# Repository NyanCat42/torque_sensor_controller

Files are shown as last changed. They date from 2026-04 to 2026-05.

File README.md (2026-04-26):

# Torque Sensor Controller for VESC E-Bike Assist

This repository contains hardware and firmware for an ESP32-S3 based torque sensor controller that talks to a [VESC](https://github.com/vedderb/bldc) over CAN bus.

The controller reads bottom bracket torque and cadence, computes an assist current target, and sends motor current commands to the VESC. It also tracks odometer data with FRAM-backed persistence and exposes a local web UI for status, tuning, and OTA firmware updates.

## Features

- Torque and cadence based pedal-assist control loop (10 ms period).
- CAN communication to VESC at 500 kbit/s.
- Odometer and speed tracking with persistent FRAM storage.
- Wi-Fi station mode with fallback access point mode.
- Embedded HTTP console for telemetry, runtime config, and calibration.
- OTA firmware upload endpoint.
- TCP bridge for VESC tool connectivity over Wi-Fi.

## Repository Layout

- `lauryno_torque_controller_hardware/`: KiCad schematic, PCB, and BOM.
- `lauryno_torque_controller_software/`: PlatformIO firmware project.
- `documents/`: reference documents, including [torque sensor datasheet](./documents/S135daff485444e569ac136541eaddd83u.pdf).
- `images/`: board render and finished board photo.

## Hardware

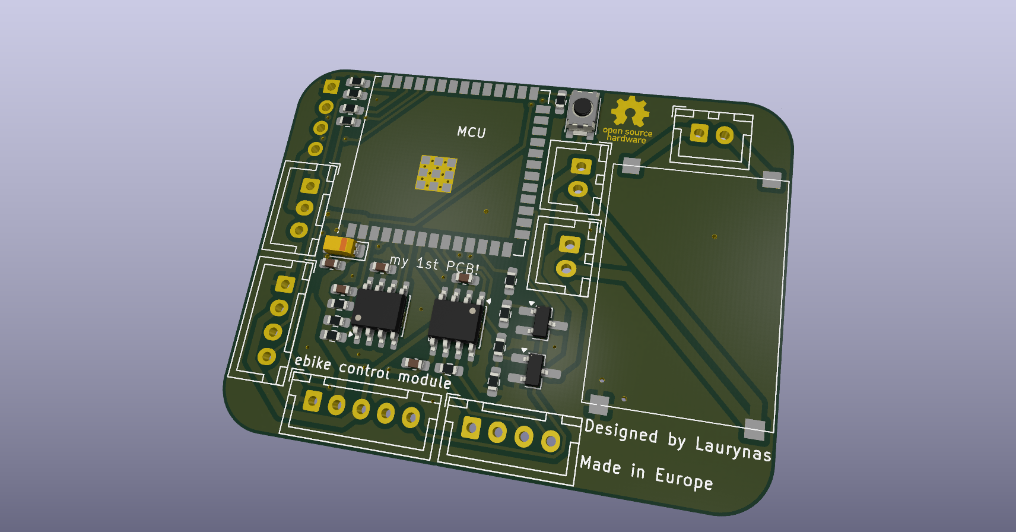
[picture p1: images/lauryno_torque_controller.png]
PCB render


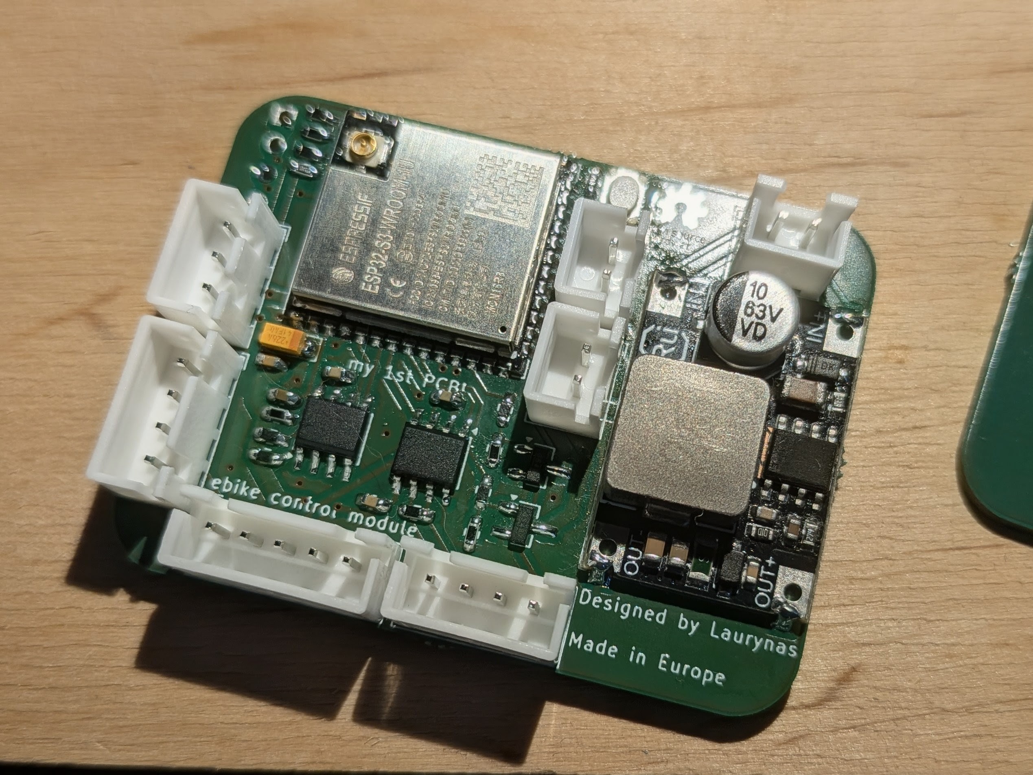
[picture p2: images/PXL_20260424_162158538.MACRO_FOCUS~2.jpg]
Finished PCB


Hardware highlights:

- ESP32-S3 module as main controller.
- CAN transceiver interface to VESC.
- FRAM storage for high-endurance persistent data.
- 2 MOSFET outputs and a buck stage for front/rear LED lighting.

The PCB was designed to fit AISLER simple 2-layer constraints for low-cost fabrication.

Available hardware design artifacts:

- Schematic: [lauryno_torque_controller.kicad_sch](./lauryno_torque_controller_hardware/lauryno_torque_controller.kicad_sch)
- PCB layout: [lauryno_torque_controller.kicad_pcb](./lauryno_torque_controller_hardware/lauryno_torque_controller.kicad_pcb)
- BOM: [lauryno_torque_controller.csv](./lauryno_torque_controller_hardware/lauryno_torque_controller.csv)

## Firmware Architecture

Main runtime modules:

- `PedalAssistManager`: torque/cadence processing and motor current command generation.
- `VescCan`: CAN transport and VESC status/current command handling.
- `OdometerManager`: wheel pulse tracking, speed estimation, and persistence.
- `FramStorage`: I2C FRAM read/write backend.
- `NetworkManager`: station connect with timeout and fallback AP startup.
- `OtaHttpServer`: web UI, REST endpoints, and OTA upload flow.
- `VescTcpBridge`: optional TCP bridge (disabled by default).

Task model:

- Pedal-assist control task on core 1.
- Communication task (HTTP + TCP bridge update loop) on core 0.
- Main loop polls CAN and updates odometer processing.

## Quick Start

First flash has to be done over UART, later ones can be done OTA.

1. Install PlatformIO CLI.
2. Open terminal in `lauryno_torque_controller_software/`.
3. Create a local `platformio.secrets.ini` (this file is git-ignored):

```ini
[env:esp32-s3-devkitc-1]
build_flags =
	-DWIFI_STA_SSID=\"YOUR_WIFI_SSID\"
	-DWIFI_STA_PASSWORD=\"YOUR_WIFI_PASSWORD\"
```

4. Build firmware:

```bash
pio run -e esp32-s3-devkitc-1
```

5. Upload over UART (pads at top left of board):

```bash
pio run -e esp32-s3-devkitc-1 -t upload
```

## First Boot Notes

- Device tries configured Wi-Fi STA first, then falls back to AP mode if connection times out.
- AP SSID format: `TorqueCtrl-Setup-<chipid>`.
- mDNS host: `lauryno-dviratis.local`.
- HTTP console runs on port `80`.
- VESC TCP bridge port: `65102` (can be toggled from API/UI).
- **Run pedal sensor zero calibration** after installation using `POST /api/pedal/calibrate_zero`.

## OTA Update

Firmware can be uploaded from the web UI or directly by HTTP multipart upload:

```bash
curl -F "file=@.pio/build/esp32-s3-devkitc-1/firmware.bin" http://lauryno-dviratis.local/api/update
```

After a successful upload, the controller restarts automatically.

## Configuration Baseline

Hardware pins:

- CAN: TX GPIO 15, RX GPIO 7, 500000 bit/s.
- Odometer hall input: GPIO 9.
- FRAM I2C: SDA GPIO 6, SCL GPIO 5, base address `0x50`.
- Torque ADC input: GPIO 1.
- Cadence input: GPIO 2.

VESC IDs: 

- Local controller `42`, target controller `69` (make sure this matches the CAN ID of your VESC).

See `lauryno_torque_controller_software/include/app_config.h` for the full set of constants and limits.

## Open-Source License

This project is licensed under **CERN Open Hardware Licence Version 2 - Permissive** (`CERN-OHL-P-2.0`).

See the repository [LICENSE](./LICENSE) file for the project license notice and the official CERN-OHL-P v2 text reference.

## References

- VESC firmware project: [https://github.com/vedderb/bldc](https://github.com/vedderb/bldc)
- Torque sensor reference document: [S135daff485444e569ac136541eaddd83u.pdf](./documents/S135daff485444e569ac136541eaddd83u.pdf)

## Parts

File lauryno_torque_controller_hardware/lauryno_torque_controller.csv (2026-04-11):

Reference | Qty | Value | DNP | Exclude from BOM | Exclude from Board | Footprint | Datasheet
Battery1,LED1,LED2 | 3 | Conn_01x02_Socket |  |  |  | Connector_JST:JST_XH_B2B-XH-A_1x02_P2.50mm_Vertical
Boot1 | 1 | SW_Push |  |  |  | Button_Switch_SMD:SW_Push_SPST_NO_Alps_SKRK
C2,C4,C5,C6 | 4 | 0.1u |  |  |  | Capacitor_SMD:C_0603_1608Metric_Pad1.08x0.95mm_HandSolder
C3 | 1 | 1u |  |  |  | Capacitor_SMD:C_0603_1608Metric_Pad1.08x0.95mm_HandSolder
C7 | 1 | 22u |  |  |  | Capacitor_Tantalum_SMD:CP_EIA-3216-18_Kemet-A_HandSolder
CAN_chip1 | 1 | TJA1051T-3 |  |  |  | Package_SO:SOIC-8_3.9x4.9mm_P1.27mm | http://www.nxp.com/docs/en/data-sheet/TJA1051.pdf
Chineesium_60V_to_12V1 | 1 | Conn_01x04_Pin |  |  |  | Connector_PinHeader_2.54mm:PinHeader_1x04_P2.54mm_Vertical
ESP32 | 1 | ESP32-S3-WROOM-1 |  |  |  | RF_Module:ESP32-S3-WROOM-1U | https://www.espressif.com/sites/default/files/documentation/esp32-s3-wroom-1_wroom-1u_datasheet_en.pdf
Flashing_UART1 | 1 | Conn_01x04_Socket |  |  |  | Connector_PinHeader_2.54mm:PinHeader_1x04_P2.54mm_Vertical
FRAM1 | 1 | FM24CL16B |  |  |  | Package_SO:SOIC-8_3.9x4.9mm_P1.27mm | https://www.infineon.com/dgdl/Infineon-FM24CL16B_16-Kbit_(2_K_8)_Serial_(I2C)_F-RAM-DataSheet-v13_00-EN.pdf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
Q1,Q2 | 2 | IRLML2502TRPBF |  |  |  | Package_TO_SOT_SMD:SOT-23_Handsoldering | https://www.infineon.com/dgdl/irlml2060pbf.pdf?fileId=5546d462533600a401535664b7fb25ee
R1,R4,R7,R8,R9,R12 | 6 | 10k |  |  |  | Resistor_SMD:R_0603_1608Metric_Pad0.98x0.95mm_HandSolder
R2 | 1 | 120 |  |  |  | Resistor_SMD:R_0603_1608Metric_Pad0.98x0.95mm_HandSolder
R5,R6 | 2 | 220 |  |  |  | Resistor_SMD:R_0603_1608Metric_Pad0.98x0.95mm_HandSolder
R10,R11 | 2 | 15k |  |  |  | Resistor_SMD:R_0603_1608Metric_Pad0.98x0.95mm_HandSolder
R13,R14 | 2 | 4.7k |  |  |  | Resistor_SMD:R_0603_1608Metric_Pad0.98x0.95mm_HandSolder
Throttle1 | 1 | Conn_01x03_Socket |  |  |  | Connector_JST:JST_XH_B3B-XH-A_1x03_P2.50mm_Vertical
Torque_sensor1,VESC_coms1 | 2 | Conn_01x04_Socket |  |  |  | Connector_JST:JST_XH_B4B-XH-A_1x04_P2.50mm_Vertical
VESC1 | 1 | Conn_01x05_Socket |  |  |  | Connector_JST:JST_XH_B5B-XH-A_1x05_P2.50mm_Vertical

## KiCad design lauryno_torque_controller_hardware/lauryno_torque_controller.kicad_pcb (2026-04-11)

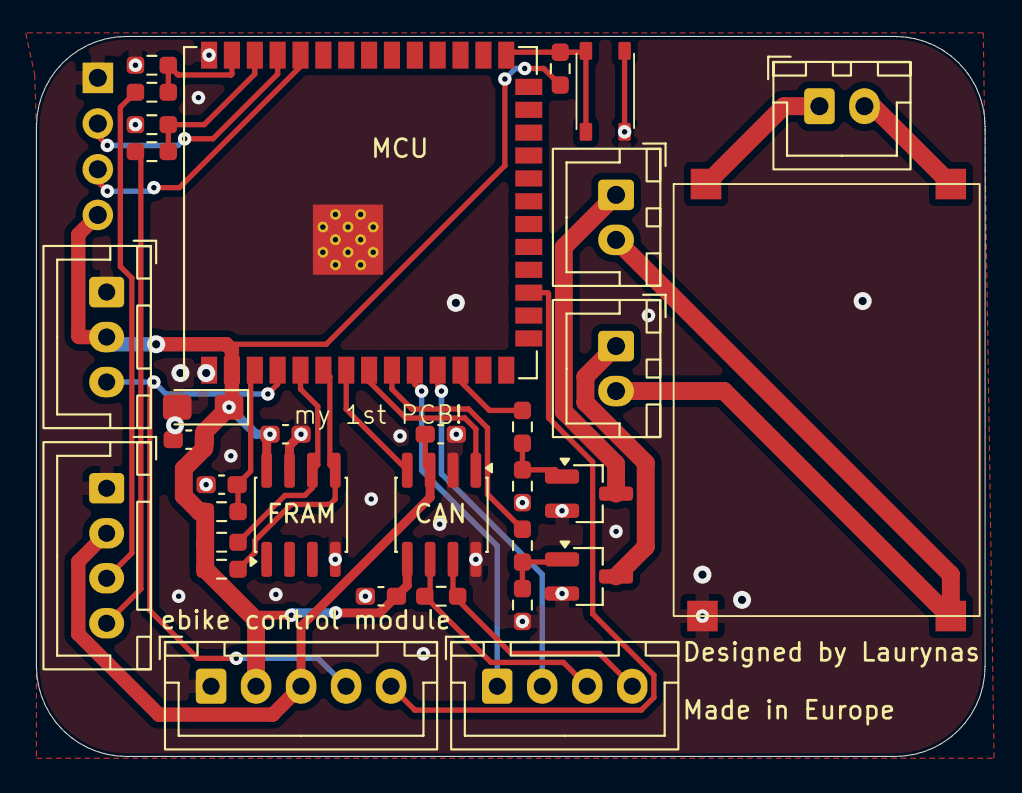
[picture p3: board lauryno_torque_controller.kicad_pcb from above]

Board: 2 copper layers, 52.7 x 40.0 mm, 34 parts (0 on the bottom side), 27 nets.

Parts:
Battery1: Conn_01x02_Socket; JST_XH_B2B-XH-A_1x02_P2.50mm_Vertical
Boot1: SW_Push; SW_Push_SPST_NO_Alps_SKRK
C2, C4, C5, C6: 0.1u; C_0603_1608Metric_Pad1.08x0.95mm_HandSolder
C3: 1u; C_0603_1608Metric_Pad1.08x0.95mm_HandSolder
C7: 22u; CP_EIA-3216-18_Kemet-A_HandSolder
CAN_chip1: TJA1051T-3; SOIC-8_3.9x4.9mm_P1.27mm
Chineesium_60V_to_12V1: Conn_01x04_Pin; PinHeader_1x04_P2.54mm_Vertical
ESP32: ESP32-S3-WROOM-1; ESP32-S3-WROOM-1U
FRAM1: FM24CL16B; SOIC-8_3.9x4.9mm_P1.27mm
Flashing_UART1: Conn_01x04_Socket; PinHeader_1x04_P2.54mm_Vertical
LED1, LED2: Conn_01x02_Socket; JST_XH_B2B-XH-A_1x02_P2.50mm_Vertical
Q1, Q2: IRLML2502TRPBF; SOT-23_Handsoldering
R1, R4, R7, R8, R9, R12: 10k; R_0603_1608Metric_Pad0.98x0.95mm_HandSolder
R2: 120; R_0603_1608Metric_Pad0.98x0.95mm_HandSolder
R5, R6: 220; R_0603_1608Metric_Pad0.98x0.95mm_HandSolder
R10, R11: 15k; R_0603_1608Metric_Pad0.98x0.95mm_HandSolder
R13, R14: 4.7k; R_0603_1608Metric_Pad0.98x0.95mm_HandSolder
Throttle1: Conn_01x03_Socket; JST_XH_B3B-XH-A_1x03_P2.50mm_Vertical
Torque_sensor1: Conn_01x04_Socket; JST_XH_B4B-XH-A_1x04_P2.50mm_Vertical
VESC1: Conn_01x05_Socket; JST_XH_B5B-XH-A_1x05_P2.50mm_Vertical
VESC_coms1: Conn_01x04_Socket; JST_XH_B4B-XH-A_1x04_P2.50mm_Vertical

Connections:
/3V3: C2.1, C4.1, C6.1, C7.1, CAN_chip1.5 (VIO), ESP32.2 (3V3), FRAM1.8 (VDD), Flashing_UART1.4, R1.1, R4.1, R13.1, R14.1, Throttle1.2, VESC1.2
/5V: C5.1, CAN_chip1.3 (VCC), Torque_sensor1.2, VESC1.3
/CAN_RX: CAN_chip1.1 (TXD), ESP32.8 (IO15)
/CAN_TX: CAN_chip1.4 (RXD), ESP32.7 (IO7)
/LED1_ctrl: ESP32.12 (IO8), R5.1
/LED2_ctrl: ESP32.9 (IO16), R6.1
/LED2_negative: LED2.1, Q2.3 (D)
/Speed: ESP32.38 (IO2), R9.2, R10.1
/Tacho: ESP32.17 (IO9), VESC1.5
/Throttle: ESP32.4 (IO4), Throttle1.3, VESC1.4
/Torque: ESP32.39 (IO1), R11.1, R12.2
/U1RXD: ESP32.11 (IO18), VESC_coms1.2
/U1TXD: ESP32.10 (IO17), VESC_coms1.1
/VLED: Chineesium_60V_to_12V1.2, LED2.2
GND: Boot1.1, C2.2, C3.1, C4.2, C5.2, C6.2, C7.2, CAN_chip1.2 (GND), CAN_chip1.8 (S), Chineesium_60V_to_12V1.3, ESP32.1 (GND), ESP32.40 (GND), ESP32.41 (GND), FRAM1.4 (VSS), FRAM1.7 (WP), Flashing_UART1.1, Q1.2 (S), Q2.2 (S), R7.1, R8.1, R10.2, R11.2, Throttle1.1, Torque_sensor1.1, VESC1.1
unnamed: CAN_chip1.7 (CANH), R2.1, VESC_coms1.4
unnamed: CAN_chip1.6 (CANL), R2.2, VESC_coms1.3
unnamed: C3.2, ESP32.3 (EN), R1.2
unnamed: Boot1.2, ESP32.27 (IO0), R4.2
unnamed: ESP32.5 (IO5), FRAM1.6 (SCL), R14.2
unnamed: ESP32.6 (IO6), FRAM1.5 (SDA), R13.2
unnamed: ESP32.36 (RXD0), Flashing_UART1.3
unnamed: ESP32.37 (TXD0), Flashing_UART1.2
unnamed: Q1.1 (G), R5.2, R7.2
unnamed: Q2.1 (G), R6.2, R8.2
unnamed: R12.1, Torque_sensor1.3
unnamed: R9.1, Torque_sensor1.4

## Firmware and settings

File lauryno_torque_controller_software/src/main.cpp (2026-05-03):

#include <Arduino.h>
#include <ESPmDNS.h>
#include <freertos/FreeRTOS.h>
#include <freertos/task.h>

#include "app_config.h"
#include "fram_storage.h"
#include "network_manager.h"
#include "odometer_manager.h"
#include "ota_http_server.h"
#include "pedal_assist_manager.h"
#include "vesc_can.h"
#include "vesc_tcp_bridge.h"

namespace {

NetworkManager g_networkManager(
    AppConfig::kStaSsid,
    AppConfig::kStaPassword,
    AppConfig::kApSsidPrefix,
    AppConfig::kApPassword,
    AppConfig::kStaConnectTimeoutMs);

VescCan g_vescCan(AppConfig::kCanTxPin,
          AppConfig::kCanRxPin,
          AppConfig::kCanBaudRate,
          AppConfig::kCanLocalControllerId,
          AppConfig::kCanTargetControllerId);

VescTcpBridge g_vescTcpBridge(
  g_vescCan, AppConfig::kVescToolTcpPort, AppConfig::kVescToolBridgeEnabledByDefault);

FramStorage g_framStorage(
  AppConfig::kOdometerI2cSdaPin,
  AppConfig::kOdometerI2cSclPin,
  AppConfig::kOdometerFramBaseAddress);

OdometerManager::Config g_odometerDefaults = []() {
  OdometerManager::Config config;
  config.wheelDiameterMm = AppConfig::kOdometerWheelDiameterMm;
  config.debounceMs = AppConfig::kOdometerDebounceMs;
  config.persistIntervalMs = AppConfig::kOdometerPersistIntervalMs;
  config.maxSpeedKmh = AppConfig::kOdometerMaxSpeedKmh;
  return config;
}();

OdometerManager g_odometerManager(
  AppConfig::kOdometerHallPin,
  AppConfig::kOdometerWheelMagnets,
  AppConfig::kOdometerSpeedStaleMs,
  AppConfig::kOdometerHardSpeedLimitKmh,
  &g_framStorage,
  g_odometerDefaults);

PedalAssistManager::Config g_pedalDefaults = []() {
  PedalAssistManager::Config config;
  config.assistRatio = AppConfig::kPedalDefaultAssistRatio;
  config.torqueRampStartNm = AppConfig::kPedalDefaultTorqueRampStartNm;
  config.torqueRampEndNm = AppConfig::kPedalDefaultTorqueRampEndNm;
  config.cadenceDisableRpm = AppConfig::kPedalDefaultCadenceDisableRpm;
  config.cadenceAverageRpm = AppConfig::kPedalDefaultCadenceAverageRpm;
  config.fastFilterAlpha = AppConfig::kPedalDefaultFastFilterAlpha;
  config.maxCurrentA = AppConfig::kPedalDefaultMaxCurrentA;
  return config;
}();

PedalAssistManager g_pedalAssistManager(
  AppConfig::kPedalTorqueAdcPin,
  AppConfig::kPedalCadencePin,
  AppConfig::kPedalCadencePulsesPerRevolution,
  AppConfig::kPedalCadenceStaleMs,
  AppConfig::kPedalControlPeriodMs,
  AppConfig::kPedalControlLateFactor,
  &g_vescCan,
  &g_framStorage,
  g_pedalDefaults);

TaskHandle_t g_pedalTaskHandle = nullptr;
TaskHandle_t g_commTaskHandle = nullptr;

constexpr uint16_t kCommTaskStackWords = 4096;
constexpr uint8_t kCommTaskPriority = 1;
constexpr uint32_t kCommTaskPeriodMs = 2;

void PedalAssistTask(void* parameter) {
  (void)parameter;
  const TickType_t periodTicks = pdMS_TO_TICKS(AppConfig::kPedalControlPeriodMs);
  TickType_t lastWake = xTaskGetTickCount();

  while (true) {
    g_pedalAssistManager.controlTick();
    vTaskDelayUntil(&lastWake, periodTicks);
  }
}

OtaHttpServer g_otaServer(
  AppConfig::kOtaHttpPort,
  &g_networkManager,
  &g_vescCan,
  &g_vescTcpBridge,
  &g_odometerManager,
  &g_pedalAssistManager);

void CommunicationTask(void* parameter) {
  (void)parameter;
  const TickType_t periodTicks = pdMS_TO_TICKS(kCommTaskPeriodMs);
  TickType_t lastWake = xTaskGetTickCount();

  while (true) {
    g_vescTcpBridge.update();
    g_otaServer.handleClient();
    vTaskDelayUntil(&lastWake, periodTicks);
  }
}

}  // namespace

void setup() {
  Serial.begin(115200);
  delay(200);

  const NetworkMode mode = g_networkManager.begin();
  const String modeLabel = (mode == NetworkMode::Station) ? "STA" : "AP";

  const bool mdnsStarted = MDNS.begin(AppConfig::kMdnsHostname);
  if (mdnsStarted) {
    MDNS.addService("http", "tcp", AppConfig::kOtaHttpPort);
    MDNS.addService("vesc", "tcp", AppConfig::kVescToolTcpPort);
    Serial.printf("[APP] mDNS ready: http://%s.local/\n", AppConfig::kMdnsHostname);
  } else {
    Serial.printf("[APP] mDNS failed to start for host: %s.local\n", AppConfig::kMdnsHostname);
  }

  const bool canReady = g_vescCan.begin();
  if (!canReady) {
    Serial.println("[APP] VESC CAN failed to initialize.");
  }

  g_vescTcpBridge.begin();

  const bool framReady = g_framStorage.begin();
  Serial.printf("[APP] FRAM ready: %s\n", framReady ? "yes" : "no");

  const bool odometerReady = g_odometerManager.begin();
  Serial.printf("[APP] Odometer ready: %s\n", odometerReady ? "yes" : "no");

  const bool pedalReady = g_pedalAssistManager.begin();
  Serial.printf("[APP] Pedal assist ready: %s\n", pedalReady ? "yes" : "no");

  const BaseType_t taskOk = xTaskCreatePinnedToCore(
      PedalAssistTask,
      "PedalAssist",
      AppConfig::kPedalTaskStackWords,
      nullptr,
      AppConfig::kPedalTaskPriority,
      &g_pedalTaskHandle,
      1);
  Serial.printf("[APP] Pedal control task: %s\n", taskOk == pdPASS ? "started" : "failed");

  const IPAddress deviceIp = g_networkManager.ipAddress();
  g_otaServer.begin(modeLabel, deviceIp);

  const BaseType_t commTaskOk = xTaskCreatePinnedToCore(
      CommunicationTask,
      "CommTask",
      kCommTaskStackWords,
      nullptr,
      kCommTaskPriority,
      &g_commTaskHandle,
      0);
  Serial.printf("[APP] Comm task (TCP+HTTP): %s\n", commTaskOk == pdPASS ? "started" : "failed");

  Serial.printf("[APP] Device IP: %s\n", deviceIp.toString().c_str());
  Serial.printf("[APP] OTA page: http://%s/\n", deviceIp.toString().c_str());
  Serial.printf("[APP] VESC TCP bridge: %s:%u\n",
                deviceIp.toString().c_str(),
                static_cast<unsigned>(AppConfig::kVescToolTcpPort));
  if (mode == NetworkMode::AccessPoint) {
    Serial.printf("[APP] AP SSID: %s\n", g_networkManager.accessPointSsid().c_str());
  }
}

void loop() {
  g_vescCan.poll();
  g_odometerManager.update();
}

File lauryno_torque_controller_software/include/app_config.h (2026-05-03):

#pragma once

#include <Arduino.h>
#include <driver/gpio.h>

namespace AppConfig {

#ifndef WIFI_STA_SSID
#define WIFI_STA_SSID "YOUR_HOME_WIFI_SSID"
#endif

#ifndef WIFI_STA_PASSWORD
#define WIFI_STA_PASSWORD "YOUR_HOME_WIFI_PASSWORD"
#endif

#ifndef WIFI_AP_SSID_PREFIX
#define WIFI_AP_SSID_PREFIX "TorqueCtrl-Setup"
#endif

#ifndef WIFI_AP_PASSWORD
#define WIFI_AP_PASSWORD "torque123"
#endif

constexpr char kStaSsid[] = WIFI_STA_SSID;
constexpr char kStaPassword[] = WIFI_STA_PASSWORD;

constexpr char kApSsidPrefix[] = WIFI_AP_SSID_PREFIX;
constexpr char kApPassword[] = WIFI_AP_PASSWORD;
constexpr char kMdnsHostname[] = "lauryno-dviratis";

constexpr uint32_t kStaConnectTimeoutMs = 15000;
constexpr uint16_t kOtaHttpPort = 80;

constexpr gpio_num_t kCanTxPin = GPIO_NUM_15;
constexpr gpio_num_t kCanRxPin = GPIO_NUM_7;
constexpr uint32_t kCanBaudRate = 500000;
constexpr uint8_t kCanLocalControllerId = 42;
constexpr uint8_t kCanTargetControllerId = 69;

constexpr uint16_t kVescToolTcpPort = 65102;
constexpr bool kVescToolBridgeEnabledByDefault = false;

constexpr gpio_num_t kOdometerHallPin = GPIO_NUM_9;
constexpr gpio_num_t kOdometerI2cSdaPin = GPIO_NUM_6;
constexpr gpio_num_t kOdometerI2cSclPin = GPIO_NUM_5;
constexpr uint8_t kOdometerFramBaseAddress = 0x50;

constexpr uint16_t kOdometerWheelDiameterMm = 659;
constexpr uint8_t kOdometerWheelMagnets = 1;
constexpr uint16_t kOdometerDebounceMs = 35;
constexpr uint32_t kOdometerSpeedStaleMs = 2500;
constexpr uint32_t kOdometerPersistIntervalMs = 30000;
constexpr float kOdometerMaxSpeedKmh = 50.0f;
constexpr float kOdometerHardSpeedLimitKmh = 50.0f;

constexpr uint16_t kOdometerMinWheelDiameterMm = 200;
constexpr uint16_t kOdometerMaxWheelDiameterMm = 900;
constexpr uint16_t kOdometerMinDebounceMs = 1;
constexpr uint16_t kOdometerMaxDebounceMs = 250;
constexpr uint32_t kOdometerMinPersistIntervalMs = 5000;
constexpr uint32_t kOdometerMaxPersistIntervalMs = 300000;

constexpr gpio_num_t kPedalTorqueAdcPin = GPIO_NUM_1;
constexpr gpio_num_t kPedalCadencePin = GPIO_NUM_2;
constexpr uint8_t kPedalCadencePulsesPerRevolution = 32;
constexpr uint32_t kPedalCadenceStaleMs = 1200;
constexpr uint32_t kPedalCadenceDebounceUs = 500;

constexpr uint8_t kPedalAdcResolutionBits = 12;
constexpr float kPedalAdcReferenceVoltage = 3.3f;
constexpr float kPedalDividerR1Ohm = 10000.0f;
constexpr float kPedalDividerR2Ohm = 15000.0f;
constexpr float kPedalSensorVoltsPerKgf = 0.035f;
constexpr float kPedalCrankLengthMeters = 0.175f;
constexpr float kPedalGravityMps2 = 9.80665f;

constexpr float kPedalFluxLinkageWb = 0.013962f;
constexpr uint8_t kPedalMotorPolePairs = 20;
constexpr float kPedalGearRatio = 5.0f;

constexpr float kPedalDefaultAssistRatio = 1.0f;
constexpr float kPedalDefaultTorqueRampStartNm = 20.0f;
constexpr float kPedalDefaultTorqueRampEndNm = 30.0f;
constexpr float kPedalDefaultCadenceDisableRpm = 8.0f;
constexpr float kPedalDefaultCadenceAverageRpm = 55.0f;
constexpr float kPedalDefaultFastFilterAlpha = 0.70f;
constexpr float kPedalDefaultMaxCurrentA = 70.0f;

constexpr float kPedalAssistRatioMin = 0.0f;
constexpr float kPedalAssistRatioMax = 3.0f;
constexpr float kPedalTorqueRampMinNm = 0.0f;
constexpr float kPedalTorqueRampMaxNm = 180.0f;
constexpr float kPedalCadenceDisableMinRpm = 0.0f;
constexpr float kPedalCadenceDisableMaxRpm = 60.0f;
constexpr float kPedalCadenceAverageMinRpm = 20.0f;
constexpr float kPedalCadenceAverageMaxRpm = 180.0f;
constexpr float kPedalFastFilterAlphaMin = 0.05f;
constexpr float kPedalFastFilterAlphaMax = 1.0f;
constexpr float kPedalCurrentLimitHardMaxA = 70.0f;

constexpr uint32_t kPedalControlPeriodMs = 10;
constexpr uint32_t kPedalControlLateFactor = 4;
constexpr uint8_t kPedalTaskPriority = 4;
constexpr uint16_t kPedalTaskStackWords = 4096;

constexpr uint16_t kPedalFramConfigAddress = 256;
constexpr uint32_t kPedalPersistIntervalMs = 30000;

}  // namespace AppConfig
